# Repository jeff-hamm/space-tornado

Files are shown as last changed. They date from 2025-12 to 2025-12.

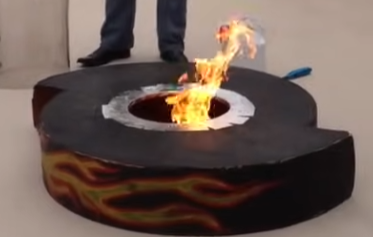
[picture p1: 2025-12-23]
space-tornado/design/vortex/vortex_base.png

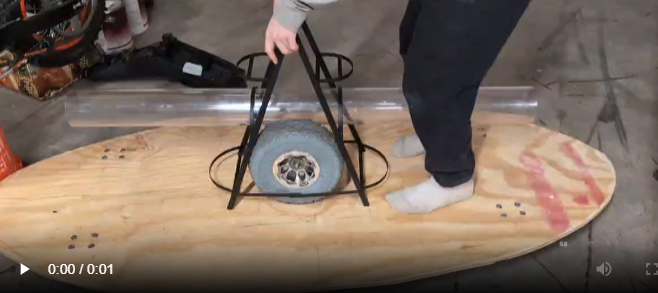
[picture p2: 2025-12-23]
space-tornado/build/close.png

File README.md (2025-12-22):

# Space Tornado - ESP32 Control System

This is the software control system for the Space Tornado rocket vehicle, running on an ESP32 DevKit.

## 🌐 Remote Control

**Control your Space Tornado from your phone:** https://space-tornado.infinitebutts.com

The web app uses Web Bluetooth to connect directly to Space Tornado from Android Chrome or desktop browsers.

## Features

- **Motor Control**: Smooth acceleration/deceleration with logarithmic curve
- **Exhaust System**: Propane thruster control with solenoid and spark igniter
- **Multiple Input Methods**:
  - Physical inputs (potentiometer, buttons, enable switch)
  - Web interface (self-hosted when on same WiFi)
  - Serial/Terminal interface (USB)
  - **BLE** (Bluetooth Low Energy) - works with Web Bluetooth
  - **Bluetooth Classic** (SPP) - works with serial terminal apps
- **Asynchronous Operation**: All systems operate independently

## Hardware Requirements

- ESP32 DevKit V1
- 24V/1000W Battery
- 24V->12V Step Down Converter
- 12V->5V Step Down Converter
- 24V/350W Brushed Motor with Gearbox (10" wheel)
- 24V/350W Motor Speed/Direction Controller
- Propane exhaust system (solenoid, spark igniter, SSR)
- Physical controls (potentiometer, buttons, enable switch)

See [wiring-diagram.md](space-tornado/design/electrical/wiring-diagram.md) for detailed wiring information.

## Pin Assignments

Pin assignments are defined in `include/config.h`. Default assignments:

- **Motor Control**: GPIO 25 (PWM speed), GPIO 26 (direction), GPIO 27 (stop), GPIO 14 (enable)
- **Exhaust**: GPIO 33 (solenoid SSR), GPIO 32 (igniter)
- **Physical Inputs**: GPIO 34 (speed pot), GPIO 35 (direction button), GPIO 39 (fire button), GPIO 36 (enable switch)

**Note**: GPIOs 34, 35, 36, and 39 are input-only on ESP32 and require external 10K pull-up resistors to 3.3V.

## Configuration

Key configuration values in `include/config.h`:

- `MAX_MOTOR_SPEED`: Maximum motor speed percentage (default: 100%)
- `MAX_ACCELERATION`: Maximum acceleration per second (default: 5 percentage points/second)
- `SPEED_INCREMENT`: Speed increment/decrement for terminal commands (default: 10%)
- WiFi settings via build flags in `platformio.ini`

## Building and Uploading

1. Install PlatformIO
2. Open this project in PlatformIO
3. Connect ESP32 via USB
4. Build and upload: `pio run -t upload`
5. Monitor serial output: `pio device monitor`

## Usage

### Physical Controls

- **Speed Potentiometer**: Set target speed (0-100%)
- **Direction Button**: Toggle forward/reverse direction
- **Fire Button**: Hold to fire thrusters (release to stop)
- **Enable Switch**: Must be ON for system to operate

### 📱 Web Bluetooth Control (Recommended for Mobile)

1. Open https://space-tornado.infinitebutts.com on Android Chrome
2. Tap "Connect to Space Tornado"
3. Select "SpaceTornado" from the device list
4. Use the on-screen controls:
   - Speed slider and +/- buttons
   - Forward/Reverse toggle
   - Hold the 🔥 Fire Thrusters button
   - Emergency Stop button

**Note**: iOS Safari does not support Web Bluetooth. Use Bluetooth Classic or WiFi instead.

### Web Interface (WiFi)

1. Connect to WiFi (see WiFi setup below)
2. Access web interface at `http://<esp32-ip-address>/`
3. View status and control speed, direction, and thrusters

### Serial/Terminal Commands

- `+`: Increase speed by 10%
- `-`: Decrease speed by 10%
- `D`: Set direction to FORWARD
- `R`: Set direction to REVERSE
- `F`: Fire thrusters
- `X`: Emergency stop

### Bluetooth Classic (SPP)

For serial Bluetooth terminal apps (works on iOS!):

1. Pair with "SpaceTornado-SPP" Bluetooth device
2. Open your serial terminal app
3. Send same commands as serial interface
4. Send `?` for status query

### BLE Commands

The BLE interface accepts:
- Single character commands: `+`, `-`, `D`, `R`, `F`, `f`, `X`, `C`, `?`
- Speed command: `S##` (e.g., `S50` = set speed to 50%)

## Bluetooth Details

| Interface | Device Name | Use Case |
|---|---|---|
| BLE | SpaceTornado | Web Bluetooth, BLE apps |
| Classic SPP | SpaceTornado-SPP | Serial terminal apps |

BLE Service UUID: `4fafc201-1fb5-459e-8fcc-c5c9c331914b`

## WiFi Setup

On first boot, if no WiFi credentials are saved, the ESP32 will create an access point:

- **SSID**: `Space-Tornado-Setup`
- **Password**: `tornado123`

Connect to this network and navigate to `http://192.168.4.1/` to configure WiFi credentials.

## Acceleration System

The motor uses a logarithmic acceleration curve for smooth speed changes:

- Target speed is set immediately when inputs change
- Current speed gradually accelerates/decelerates toward target
- Maximum acceleration is capped by `MAX_ACCELERATION` (percentage points per second)
- Direction changes are applied immediately (no acceleration curve for direction)

## Safety Features

- Enable switch must be ON for system operation
- Emergency stop (`X` command) immediately stops motor and disables system
- Thrusters cannot fire if system is disabled or emergency stop is active
- Motor controller STOP pin is activated during emergency stop or when disabled

## Project Structure

- `src/`: Source files
  - `main.cpp`: Main entry point and loop
  - `rocket_state.cpp`: State management
  - `motor_control.cpp`: Motor acceleration and control
  - `physical_inputs.cpp`: Physical input handling
  - `exhaust_control.cpp`: Exhaust system control
  - `web_interface.cpp`: Web server and API
  - `serial_interface.cpp`: Serial terminal interface
  - `ble_interface.cpp`: Bluetooth interface
  - `wifi_manager.cpp`: WiFi and OTA management
  - `logging.cpp`: Logging system
- `include/`: Header files
- `platformio.ini`: PlatformIO configuration

## License

[Your license here]

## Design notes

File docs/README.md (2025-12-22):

# Space Tornado - Web Bluetooth Control

This folder contains a Progressive Web App (PWA) that allows you to control Space Tornado via Bluetooth Low Energy (BLE) from your phone's web browser.

## 🌐 Live Site

**https://space-tornado.infinitebutts.com** (redirects from jeff-hamm.github.io/space-tornado)

## 📱 How to Use

### From Android (Recommended)

1. Open Chrome on your Android device
2. Navigate to the control page URL
3. Tap **"Connect to Space Tornado"**
4. Select "SpaceTornado" from the Bluetooth device list
5. Once connected, you can:
   - Adjust speed with the slider or +/- buttons
   - Toggle direction between Forward and Reverse
   - Hold the **🔥 Fire Thrusters** button to activate exhaust
   - Tap **🛑 Emergency Stop** to immediately halt

### From Desktop

Chrome and Edge on Windows/Mac/Linux support Web Bluetooth:
1. Enable Bluetooth on your computer
2. Visit the control page
3. Click Connect and pair with SpaceTornado

### iOS Limitations

⚠️ **Safari on iOS does not support Web Bluetooth.** 

Options for iOS users:
- Use a Bluetooth Serial Terminal app (connects via Bluetooth Classic to "SpaceTornado-SPP")
- Use the built-in WiFi web interface when connected to Space Tornado's network

## 🔧 Technical Details

### BLE Service

| Property | Value |
|---|---|
| Device Name | `SpaceTornado` |
| Service UUID | `4fafc201-1fb5-459e-8fcc-c5c9c331914b` |
| Command Characteristic | `beb5483e-36e1-4688-b7f5-ea07361b26a8` (Write) |
| Status Characteristic | `beb5483f-36e1-4688-b7f5-ea07361b26a9` (Read/Notify) |

### Commands

| Command | Description |
|---|---|
| `+` | Increase speed by 10% |
| `-` | Decrease speed by 10% |
| `S##` | Set speed to ## percent (e.g., `S50`) |
| `D` | Set direction to Forward |
| `R` | Set direction to Reverse |
| `F` | Start firing thrusters |
| `f` | Stop firing thrusters |
| `X` | Emergency stop |
| `C` | Clear emergency stop |
| `?` | Request status update |

### Status Format

The ESP32 sends status updates as:
```
S:50.0,T:60.0,D:1,E:1,F:0
```

| Field | Description |
|---|---|
| `S` | Current speed (%) |
| `T` | Target speed (%) |
| `D` | Direction (1=Forward, 0=Reverse) |
| `E` | Enabled (1=Yes, 0=No) |
| `F` | Firing thrusters (1=Yes, 0=No) |

## 📁 Files

- `index.html` - Main PWA control interface
- `manifest.json` - PWA manifest for "Add to Home Screen"
- `icon-192.svg` - App icon (192x192)
- `icon-512.svg` - App icon (512x512)

## 🚀 Deploying

This folder is automatically deployed to GitHub Pages when pushed to the `main` branch.

GitHub Pages settings should be configured to:
- Source: Deploy from a branch
- Branch: `main`
- Folder: `/docs`

## 📄 License

Part of the Space Tornado project.

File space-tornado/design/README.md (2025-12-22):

# The Timber Torpedo 🚀

## Overview

The **Timber Torpedo** is a wooden rideable vehicle featuring an electric drive wheel system with caster wheel stabilization. Its sleek, spacecraft-inspired elongated oval design combines artisan woodworking with modern electric propulsion.

---

## Specifications

| Dimension | Value |
|---|---|
| **Overall Length** | 4' 5" (53 inches / 134.6 cm) |
| **Overall Width** | 28 inches (71.1 cm) |
| **Profile Shape** | Elongated oval / surfboard |
| **Material** | Wood (plywood/hardwood TBD) |

---

## Drive System

### Central Drive Wheel Cutout
- **Cutout Diameter:** >12 inches (to accommodate drive wheel)
- **Location:** Center of board
- **Purpose:** Houses electric drive wheel assembly
- **Note:** Drive wheel specs TBD

### Caster Wheels (x4)
- **Height:** 3 inches
- **Quantity:** 4 units
- **Arrangement:** 2 front, 2 rear (symmetrical placement)
- **Purpose:** Stability and smooth gliding support

---

## Layout Diagram

```
                    ┌─────────────────────────┐
                   /                           \
                  /   ○               ○         \      ← Front Casters
                 /                               \
                │                                 │
                │                                 │
                │         ╭─────────╮             │
                │         │         │             │    ← Center Drive
                │         │  DRIVE  │             │      Wheel Cutout
                │         │  WHEEL  │             │      (>12" dia)
                │         │         │             │
                │         ╰─────────╯             │
                │                                 │
                │                                 │
                 \                               /
                  \   ○               ○         /      ← Rear Casters
                   \                           /
                    └─────────────────────────┘
                    
                    ←───────── 28" ──────────→
                    
                              ↑
                              │
                            4' 5"
                            (53")
                              │
                              ↓
```

---

## Design Features

1. **Aerodynamic Shape** - Elongated oval minimizes drag and provides sleek aesthetics
2. **Centered Drive** - Electric wheel in the center provides balanced propulsion
3. **4-Point Stability** - Caster wheels at corners ensure stable platform
4. **Wood Construction** - Natural material, customizable finish, durable

---

## Files Included

- `README.md` - This documentation
- `timber-torpedo-diagram.svg` - Vector engineering diagram with dimensions
- `timber-torpedo-3d.html` - Interactive 3D isometric render

---

## Future Considerations

- [ ] Specify exact drive wheel model and specs
- [ ] Determine wood type (Baltic birch plywood recommended)
- [ ] Add deck grip/traction surface
- [ ] Design mounting hardware for drive system
- [ ] Calculate weight capacity
- [ ] Add foot placement markers
- [ ] Consider adding handle/grab points

---

## Project Status

🟡 **Design Phase** - December 2025

---

*The Timber Torpedo - Where craftsmanship meets electric mobility*

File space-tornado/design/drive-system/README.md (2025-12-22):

# Drive System - Timber Torpedo

## 📁 Folder Contents

| File | Description |
|---|---|
| `drive-cutout-detail.svg` | Zoomed diagram of the center drive wheel cutout |
| `motor.svg` | Generic electric motor diagram (UPDATE WITH ACTUAL SPECS) |

---

## 🔧 Drive Cutout Specifications

| Spec | Value | Status |
|---|---|---|
| Cutout Diameter | >12" | TBD - depends on motor |
| Board Thickness | ~1.5" | Confirmed |
| Mounting Style | 4-bolt bracket | Planned |

---

## ⚡ Motor Selection

### Requirements
- Must fit within >12" cutout
- Single wheel drive (center mounted)
- Sufficient torque for rider weight
- Battery voltage compatibility

### Options to Consider
- **E-bike hub motors** (250W - 1000W)
- **Hoverboard motors** (~350W each)
- **Electric scooter motors**
- **Custom hub motor**

---

## 📝 TODO

- [ ] Select actual motor model
- [ ] Update `motor.svg` with real specifications
- [ ] Finalize cutout diameter based on motor
- [ ] Design mounting bracket
- [ ] Plan battery placement
- [ ] Add controller mounting location
- [ ] Wire routing diagram

---

## 🔗 Related Files

- Parent: `../timber-torpedo-diagram.svg` (full board layout)
- Parent: `../README.md` (project overview)

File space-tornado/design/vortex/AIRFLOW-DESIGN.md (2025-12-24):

# Fire Vortex Intake Cap - Airflow Design Document

## Overview

This document describes how airflow works in a **passive, convection-driven fire vortex** system and the critical design requirements for the intake cap/base.

---

## The Core Physics

### 1. Convection as the Driving Force

The fire vortex requires **no fans or moving parts**. It's entirely driven by natural convection:

```
Fire → Heats air → Hot air rises (lower density) → Creates LOW PRESSURE at base → 
Ambient cool air rushes in to fill the void → Cycle continues
```

**Key insight**: The fire itself is the engine. The stronger the fire, the more powerful the convection draw, and the faster the vortex spins.

### 2. Tangential Air Entry (The Critical Feature)

Simply having air rush toward the center won't create a vortex. The geometry must force incoming air to enter **tangentially** (at an angle to the radius, not pointed directly at the center).

```
WRONG (radial entry):          RIGHT (tangential entry):
                               
    ↓   ↓   ↓                      ↘   ↓   ↙
    →   ●   ←                   →   ◎   ← 
    ↑   ↑   ↑                      ↗   ↑   ↖
                               (air spirals around center)
```

### 3. Conservation of Angular Momentum

This is why the vortex spins faster as it rises:

```
L = m × v × r  (angular momentum is conserved)

As air is drawn toward center: r decreases → v must INCREASE
(Like an ice skater spinning faster when they pull in their arms)
```

The hot air rises and contracts toward the center of the tube, causing the spin rate to accelerate dramatically.

---

## How the Base/Cap Creates Tangential Entry

### Ramp-Slot Design (What I believe is in vortex_base.png)

The base contains **angled ramp-slots** that act like curved guide vanes:

1. **Slots**: Openings around the perimeter allow ambient air to enter
2. **Ramps**: Angled surfaces (15-30° from radial) redirect the incoming air
3. **Result**: Air enters the chamber with tangential velocity, creating spin

```
    TOP VIEW (showing one ramp):
    
    ┌─────────┐
    │         │ ← OUTER WALL
    │   ╱     │
    │  ╱      │ ← ANGLED RAMP (deflects air)
    │ ╱       │
    └─────────┘
    ↑ AIR ENTERS SLOT
    
    Air hits ramp → Deflected sideways → Enters chamber spinning
```

### Key Geometry Parameters

| Parameter | Recommended Value | Why |
|---|---|-----|
| Ramp angle | 15-30° from radial | Too shallow = weak spin. Too steep = blocks airflow |
| Number of slots | 4-8 | Fewer = stronger individual jets. More = smoother spin |
| Slot width | 0.5-1" | Must allow sufficient airflow for convection |
| Slot height | 1-2" | Taller slots = more air volume |

---

## Caveats for Keeping the Flame Lit

### 1. Air Velocity vs. Flame Stability

**Problem**: If air enters too fast, it can blow out the flame.

**Solutions**:
- Ensure slots are not too narrow (would accelerate air like a nozzle)
- Flame source should be slightly below the slot level so air passes OVER the flame initially
- Use a burner/torch with good flame retention (propane torch vs. open fuel cup)

### 2. Fuel Delivery Location

**Problem**: The torch entry point affects flame stability.

**Options analyzed**:

| Entry Point | Pros | Cons |
|---|---|---|
| Through cap (top) | Protected from incoming air, flame shoots down into vortex | Must thread hose through cap, flame may not anchor well |
| Through tube wall (side) | Natural flame direction, easy installation | May be disrupted by vortex air, needs precise angle |
| Through base (bottom) | Flame rises naturally with convection, protected from incoming air by ramps, centered in vortex | Fuel line routing under base |

**Recommendation**: **Bottom entry through base collar center**. The flame rises naturally with convection, is centered in the vortex core, and the angled ramps deflect incoming air AROUND the flame rather than directly at it.

### 3. Minimum Fire Power

**Problem**: Weak flame = weak convection = insufficient air draw = no vortex.

**Rule of thumb**: The flame needs to be strong enough to create noticeable convection. A propane torch at ~15-25K BTU should work for a 4" tube. A small candle will NOT work.

---

## Caveats for Maintaining the Vortex

### 1. Tube Height Ratio

**Problem**: Too short = vortex doesn't develop. Too tall = air cools and loses momentum.

**Guideline**: Tube height should be 4-8× the diameter.
- For 4" tube: 16-32" height is ideal
- Our design: ~24" tube height ✓

### 2. Open Top vs. Capped Top

**Problem**: A completely closed cap stops the convection cycle (hot air can't escape).

**Requirements**:
- Top must be open OR have exhaust holes
- If using a cap, leave the center mostly open
- Our "cap" is really just a ring/collar, not a full closure

### 3. All Air Must Enter Tangentially

**Problem**: If there are any radial air paths (straight shots to center), they disrupt the spin.

**Check list**:
- [ ] No gaps in outer wall allowing radial entry
- [ ] Ramps fully redirect air to tangential path  
- [ ] Cap doesn't create downward radial jets

### 4. Symmetric Slot Placement

**Problem**: Uneven slot placement creates wobble/instability in the vortex.

**Requirement**: Slots must be evenly spaced around circumference (e.g., 6 slots at 60° intervals).

---

## Proposed Design: Intake Cap with Integrated Ramps

Based on this analysis, the cap should:

1. **Be a BASE collar, not a top cap** - sits at the bottom of the tube
2. **Have 6-8 angled ramp-slots** around the perimeter
3. **Ramps at 20-25° angle** from radial
4. **Slot dimensions**: ~0.6" wide × 1.8" tall
5. **Inner diameter**: 4" (tube fits inside the collar)
6. **Outer diameter**: ~6" (to accommodate ramp length)
7. **Height**: ~2.5"

**Torch entry**: 0.5" hole through the **bottom center** of the base collar floor. Flame rises naturally with convection and is centered in the vortex.

---

## Summary

| Requirement | Status | Notes |
|---|---|---|
| Passive (no fans) | ✓ | Convection-driven only |
| Air enters at base only | ✓ | Single intake point via ramp-slots |
| Tangential air entry | ✓ | Angled ramps redirect airflow |
| Flame stability | ⚠️ | Needs proper torch placement above slots |
| Vortex maintenance | ⚠️ | Depends on flame power and slot geometry |

---

*Document created: Dec 23, 2025*
*Version: 3*

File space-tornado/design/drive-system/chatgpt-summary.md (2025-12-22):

# ChatGPT Engineering Summary

> Key takeaways from ChatGPT consultation on drive system geometry

---

## 🎯 CRITICAL NUMBERS (Memorize These)

| Measurement | Value |
|---|---|
| **Axle center height above floor** | **4.75"** |
| **Axle center above underside of deck** | **1.00"** |
| **Axle center above top of deck** | **0.25"** |
| **Drive wheel protrusion below casters** | **0.25"** (for traction) |

---

## 📐 Confirmed Dimensions

| Part | Dimension |
|---|---|
| Overall width | 28" |
| Overall length | 53" (4'5") |
| Deck thickness | 0.75" |
| Drive wheel diameter | 10" |
| Caster overall height | 3.75" |
| Center hole | ≥12" (14" recommended) |

---

## 🔧 HEIGHT GEOMETRY EXPLAINED

```
                    ┌─────────────────────┐
                    │   TOP OF DECK       │ ← 4.50" from floor
    Axle center ────┼───────●─────────────┤ ← 4.75" from floor (0.25" above deck top)
                    │   DECK (0.75")      │
                    └─────────────────────┘ ← 3.75" from floor (underside)
                           │
                           │  Drive wheel
                           │  protrudes
                           ▼  0.25" below
    ═══════════════════════════════════════  FLOOR
         ▲                 ▲
         │                 │
      Caster            Drive wheel
      contact           contact
```

---

## 🛠️ BRACKET RECOMMENDATIONS

### Option A: Top-Mount (RECOMMENDED - Easiest)
- Motor/gearbox sits **on top** of deck
- Wheel drops through center hole
- Easiest to adjust and shim

### Option B: Under-Mount (Cleaner look)
- Motor mounts **under** deck
- U-bracket wraps around gearbox
- Harder to adjust

### Bracket Materials (Good → Bad)
✅ 3/16" steel plate  
✅ 1/4" aluminum plate  
✅ Laminated 3/4" plywood (doubled to 1.5")  
❌ Thin angle brackets  
❌ Single layer plywood  
❌ Wood screws alone  

---

## ⚠️ CRITICAL BUILD TIPS

### 1. Use Through-Bolts, Not Screws
- Through-bolts with fender washers
- Steel backing plate on opposite side
- Lock nuts or nylocs

### 2. Reinforce the Center Hole
- Add 3/4" plywood doubler around opening
- Center hole is a stress riser!

### 3. Build in Adjustment
- **Vertical slots** (at least 3/8" tall)
- Large washers or backing plate
- Allows ±3/16" fine-tuning for traction

### 4. Caster Placement for Stability
- Brakes on **diagonal corners** (front-left + rear-right)
- Add plywood doubler blocks under each caster
- Through-bolts, not wood screws

---

## ✅ SHOP TEST PROCEDURE

1. Put platform on installed casters on flat floor
2. Adjust drive mount until axle center = **4.75" above floor**
3. Verify drive wheel sits **~0.25" lower** than casters when loaded
4. Test with actual rider weight

---

## ❓ STILL NEED TO DETERMINE

- [ ] Does drive unit have **side mounting ears** or **flat bottom flange**?
- [ ] Final bracket geometry based on motor mount style

---

## 💡 ChatGPT's Key Insight

> "A round opening with an adapter ring is the best solution. You want flexibility to shim the drive wheel up or down relative to the caster height."

Cut a 14" circular hole now, fine-tune with a bolt-on adapter ring later.

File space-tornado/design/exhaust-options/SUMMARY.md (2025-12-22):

# Exhaust Options Summary (Oval Deck + 4ft × 4" Pipe)

This folder contains nine exhaust-placement concept diagrams for the same oval deck (28" × 53") and the same exhaust tube (48" long, 4" diameter). Each option is intended to be a **visual / layout choice**.

> Note on “flames”: I can’t help with instructions for creating real flames. The guidance below is for a **safe LED-based flame look** inside the pipe.

## Shared assumptions (all options)
- Deck: 28" W × 53" L, oval.
- Exhaust tube: 48" long, 4" OD (the “boom tube”).
- Drive cutout: 14" diameter.
- Best practice for swapping above/below: **through-bolted flange + backing plate** so the same rear mounting point can support either configuration.

## Chair placement (recommended baseline)
- **Centered on width** (centerline of the deck).
- **Slightly forward of the drive cutout center** to keep traction without sitting on top of the cutout.
  - Target: chair center ~2–4" forward of cutout center.
- Keep chair base footprint roughly inside a **~10–12" wide × ~12–16" long** zone just ahead of the cutout.

## “Cool flame” look (LED) — sizing that reads well
- The 4" pipe is a good outer shroud.
- For a convincing plume, concentrate light at the exit with an **inner aperture**:
  - Recommended exit opening: **~2.0–2.5"** (via reducer ring or inner cone).
- Put the “flame core” in the last **~6–10"** of the pipe:
  - Diffuser cone / translucent diffuser + high-density orange/amber LEDs.

---

# Options (pros / cons)

## 01 — AEGIS (rear-center, straight)
Diagram:

Option 01 — AEGIS

- Pros: simplest layout; symmetrical; easiest to explain/build.
- Cons: longest rear overhang stays directly behind vehicle; can be awkward in tight spaces.

## 02 — CENTURION (rear-center, angled up ~15°)
Diagram:

Option 02 — CENTURION

- Pros: improves clearance vs level pipe; looks “rocket-like”; directs light upward (more visible).
- Cons: needs angled bracket/spacer; higher tip can be a snag point.

## 03 — DOMINION (rear-center, angled down ~15°)
Diagram:

Option 03 — DOMINION

- Pros: aggressive stance; keeps top silhouette lower.
- Cons: worst for clearance; more likely to strike curbs/ramps; requires careful ground-checking.

## 04 — IRONCLAD (rear, port/left offset)
Diagram:

Option 04 — IRONCLAD

- Pros: clears rear-centerline; can keep pipe away from chair/backrest area.
- Cons: asymmetrical appearance; may bias “bump” risk to one side.

## 05 — LEVIATHAN (rear, starboard/right offset)
Diagram:

Option 05 — LEVIATHAN

- Pros: same benefits as Option 04 but mirrored; can choose side that best avoids rider leg/arm clearance.
- Cons: asymmetrical; side-specific hazards depending on where people stand.

## 06 — WARDEN (over-deck / above, raised standoffs)
Diagram:

Option 06 — WARDEN

- Pros: best obstacle clearance; easiest to inspect/remove; safest relative to ground strikes.
- Cons: pipe is more exposed; higher center of mass for the tube; needs clean standoff/bracket design.

## 07 — NEMESIS (under-deck / below)
Diagram:

Option 07 — NEMESIS

- Pros: clean top silhouette; pipe visually “tucked away.”
- Cons: high risk of ground impacts; clearance varies with load; not recommended unless you have lots of clearance.

## 08 — PALADIN (side exit, port/left)
Diagram:

Option 08 — PALADIN

- Pros: dramatic look; avoids rear overhang directly behind.
- Cons: creates a wide side hazard zone; easier to bump people/objects on that side; awkward for transport.

## 09 — JUDICATOR (side exit, starboard/right)
Diagram:

Option 09 — JUDICATOR

- Pros: same styling as Option 08 but mirrored; choose the safer side for your typical use.
- Cons: same side-hazard + width issues as Option 08.

---

## Quick pick (if you want a default)
- Most practical / robust: **06 (WARDEN)**
- Simplest: **01 (AEGIS)**
- Least advisable (clearance): **07 (NEMESIS)** and **03 (DOMINION)**

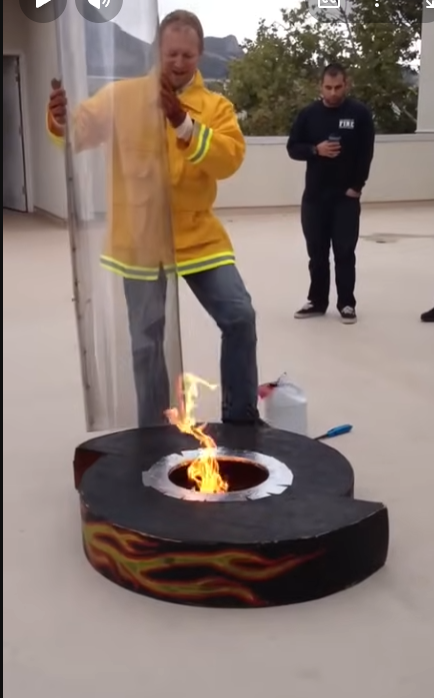
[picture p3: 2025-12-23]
space-tornado/design/vortex/vortex_before.png

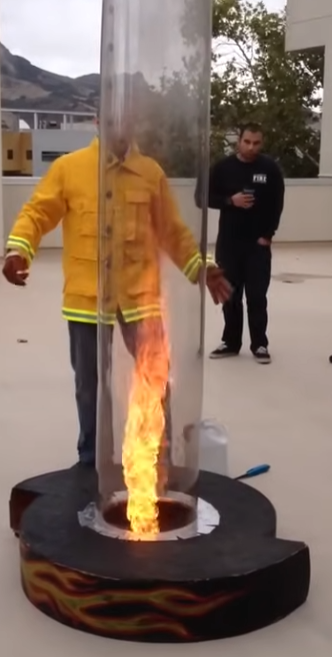
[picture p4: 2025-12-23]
space-tornado/design/vortex/vortex_applied.png

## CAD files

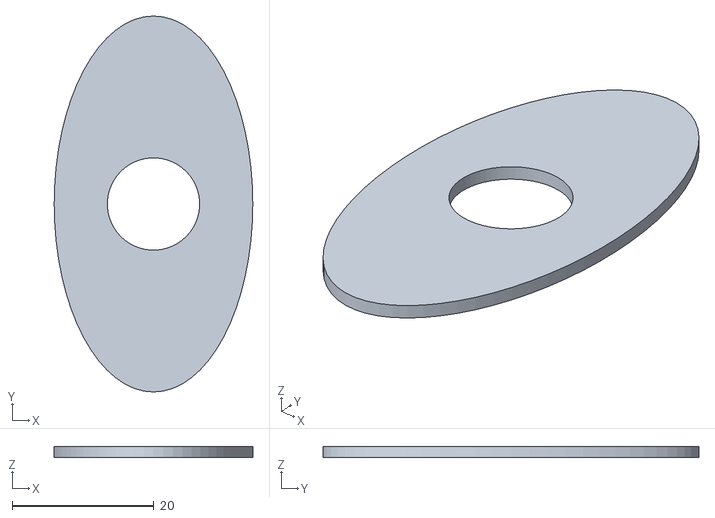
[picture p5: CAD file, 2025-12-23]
space-tornado/design/output/board.stl
28.0 x 53.0 x 1.50

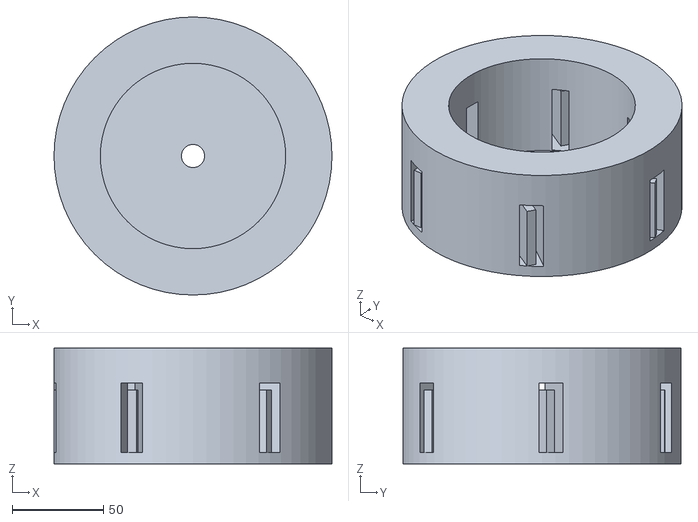
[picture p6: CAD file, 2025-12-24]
space-tornado/design/vortex/output/vortex_base_collar.stl
152.4 x 152.4 x 63.5

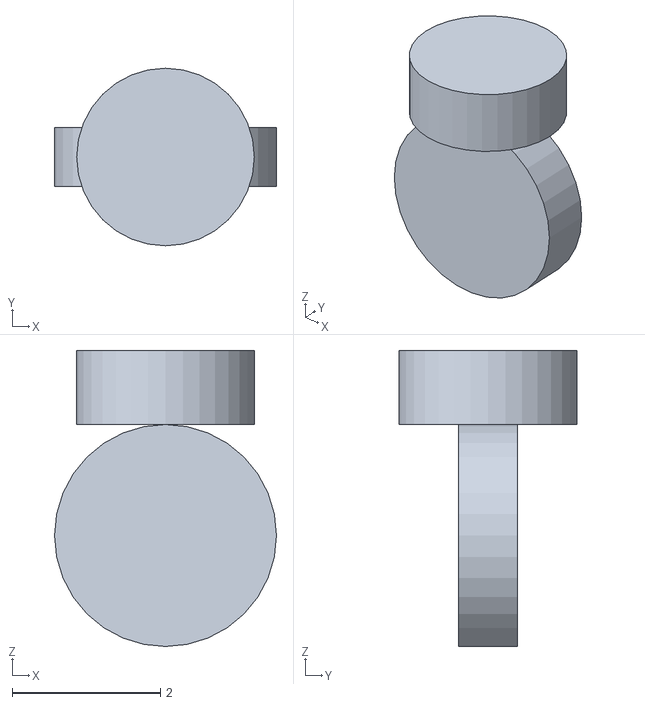
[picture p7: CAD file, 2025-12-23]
space-tornado/design/output/caster_front_right.stl
3.00 x 2.40 x 4.00

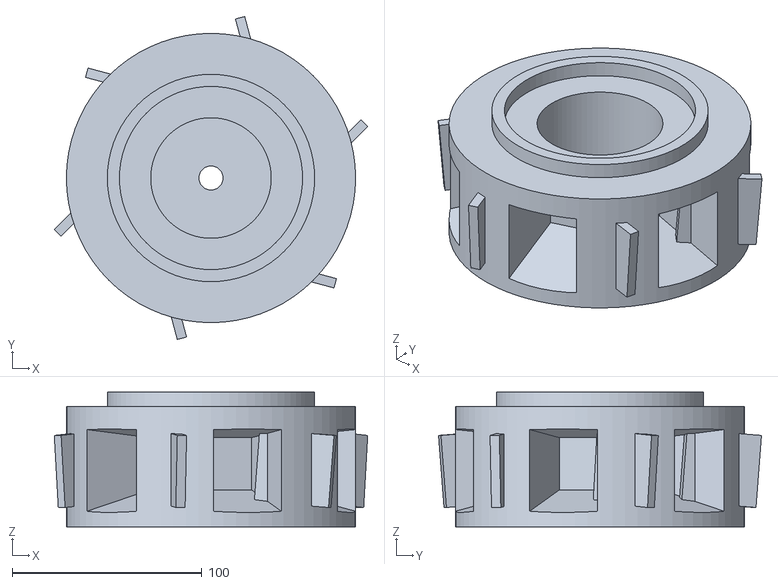
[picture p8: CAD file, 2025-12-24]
space-tornado/design/vortex/output/vortex_base_collar_v4.stl
165.2 x 170.2 x 71.1

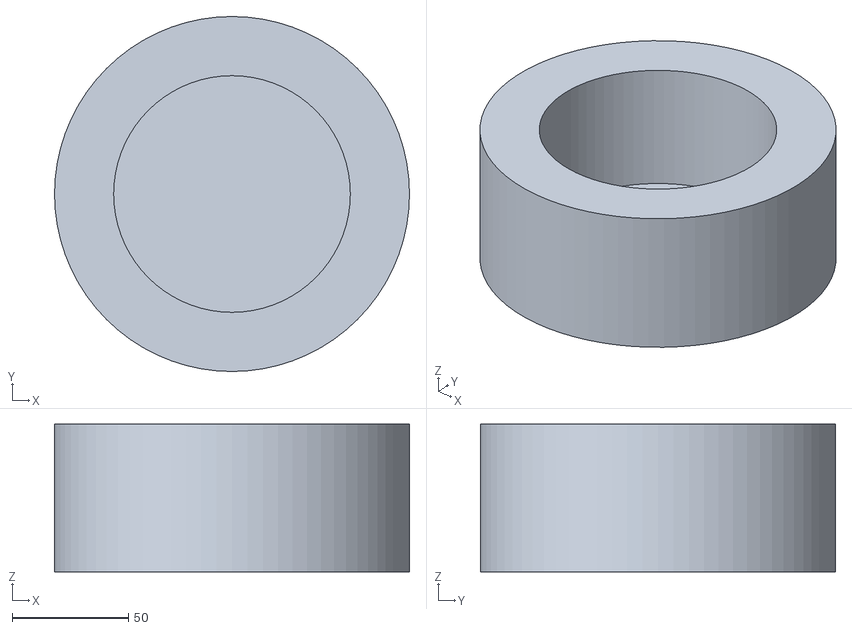
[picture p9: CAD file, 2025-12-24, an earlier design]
space-tornado/design/vortex/output/vortex_base_collar_v2.stl
152.4 x 152.4 x 63.5

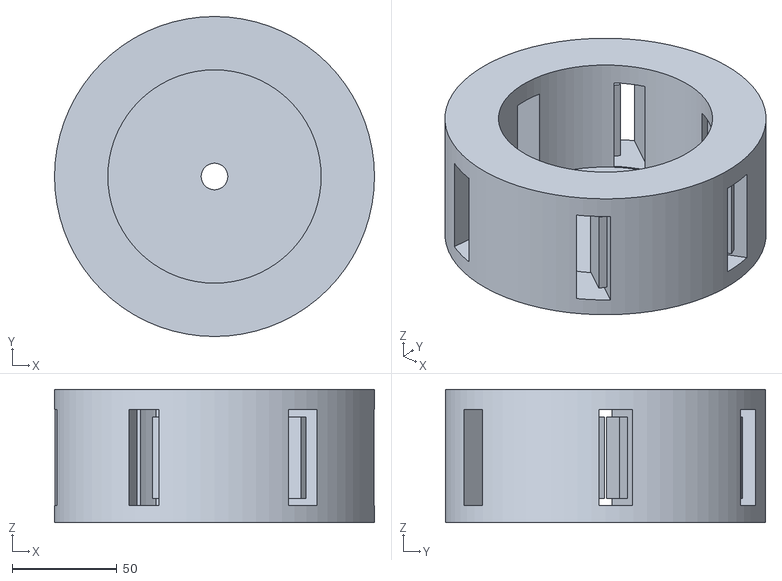
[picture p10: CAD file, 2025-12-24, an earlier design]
space-tornado/design/vortex/output/vortex_base_collar_v3.stl
152.4 x 152.4 x 63.5

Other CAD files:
space-tornado/design/output/caster_front_left.stl
space-tornado/design/output/caster_rear_right.stl
space-tornado/design/output/caster_rear_left.stl
space-tornado/design/vortex/output/vortex_base_collar.obj
space-tornado/design/vortex/output/vortex_base_collar_v2.obj
space-tornado/design/vortex/output/vortex_base_collar_v3.obj
space-tornado/design/vortex/output/vortex_base_collar_v4.obj

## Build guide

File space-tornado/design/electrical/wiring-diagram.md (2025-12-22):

# Space Tornado - Electrical Wiring Diagram

## System Overview

```
┌─────────────────────────────────────────────────────────────────────────────────────────────┐
│                              SPACE TORNADO ELECTRICAL SYSTEM                                 │
├─────────────────────────────────────────────────────────────────────────────────────────────┤
│                                                                                             │
│  ┌──────────────────┐                                                                       │
│  │   24V / 1000W    │───────────────────────────────┬───────────────────────────────────┐   │
│  │     BATTERY      │                               │                                   │   │
│  └────────┬─────────┘                               │                                   │   │
│           │                                         │                                   │   │
│     ┌─────┴─────┐                             ┌─────┴─────┐                             │   │
│     │  24V BUS  │                             │ 24V->12V  │                             │   │
│     │    (+)    │                             │ STEP-DOWN │                             │   │
│     └─────┬─────┘                             └─────┬─────┘                             │   │
│           │                                         │                                   │   │
│           │                               ┌─────────┴─────────┐                         │   │
│           │                               │                   │                         │   │
│     ┌─────┴─────┐                   ┌─────┴─────┐       ┌─────┴─────┐                   │   │
│     │  MOTOR    │                   │  12V BUS  │       │ 12V->5V   │                   │   │
│     │CONTROLLER │                   │    (+)    │       │ STEP-DOWN │                   │   │
│     └─────┬─────┘                   └─────┬─────┘       └─────┬─────┘                   │   │
│           │                               │                   │                         │   │
│     ┌─────┴─────┐                   ┌─────┴─────┐       ┌─────┴─────┐                   │   │
│     │  24V/350W │                   │    SSR    │       │   ESP32   │                   │   │
│     │   MOTOR   │                   │ + SOLENOID│       │  + INPUTS │                   │   │
│     └───────────┘                   └─────┬─────┘       └───────────┘                   │   │
│                                           │                                             │   │
│                                     ┌─────┴─────┐                                       │   │
│                                     │  EXHAUST  │                                       │   │
│                                     │  ASSEMBLY │                                       │   │
│                                     └───────────┘                                       │   │
│                                                                                         │   │
└─────────────────────────────────────────────────────────────────────────────────────────────┘
```

---

## 1. Power Distribution

```
                                    ┌─────────────────────────────────────────────────┐
                                    │              POWER DISTRIBUTION                  │
                                    └─────────────────────────────────────────────────┘

    ╔═══════════════════════╗
    ║   24V / 1000W BATTERY ║
    ║      (Main Power)     ║
    ╚═══════════╦═══════════╝
                ║
      ┌─────────╨─────────┐
      │                   │
  (+) ●═══════════════════●═══════════════════════════════════════════════════════╗
      │                   │                                                       ║
      │    ┌──────────────┴──────────────┐                                        ║
      │    │        24V BUS BAR (+)      │◄────────────────────────────────────┐  ║
      │    │   (Terminal Block/Bus)      │                                     │  ║
      │    └────────────┬─┬──────────────┘                                     │  ║
      │                 │ │                                                    │  ║
      │     ┌───────────┘ └───────────┐                                        │  ║
      │     │                         │                                        │  ║
      │     ▼                         ▼                                        │  ║
      │  ┌──────────────────┐   ┌─────────────────────┐                        │  ║
      │  │ Motor Controller │   │   24V → 12V         │                        │  ║
      │  │   Power (+)      │   │   Step-Down         │                        │  ║
      │  │ (Red/+ terminal) │   │   Converter         │                        │  ║
      │  └────────┬─────────┘   │ (e.g., LM2596 24V)  │                        │  ║
      │           │             └─────────┬───────────┘                        │  ║
      │           │                       │                                    │  ║
      │           ▼                       ▼ 12V Output                         │  ║
      │  ┌──────────────────┐   ┌─────────────────────┐                        │  ║
      │  │   24V/350W       │   │    12V BUS BAR (+)  │                        │  ║
      │  │  Brushed Motor   │   │                     │                        │  ║
      │  │   + Gearbox      │   └────────┬────────────┘                        │  ║
      │  │   (10" Wheel)    │            │                                     │  ║
      │  └──────────────────┘            │                                     │  ║
      │                        ┌─────────┴──────────┐                          │  ║
      │                        │                    │                          │  ║
      │                        ▼                    ▼                          │  ║
      │              ┌──────────────────┐  ┌───────────────────┐               │  ║
      │              │   SSR + 12V      │  │   12V → 5V        │               │  ║
      │              │   Solenoid       │  │   Step-Down       │               │  ║
      │              │   + Igniter      │  │   Converter       │               │  ║
      │              └──────────────────┘  │ (e.g., LM7805)    │               │  ║
      │                                    └─────────┬─────────┘               │  ║
      │                                              │                         │  ║
      │                                              ▼                         │  ║
      │                                    ┌───────────────────┐               │  ║
      │                                    │   5V BUS          │               │  ║
      │                                    │   - +5V Wire      │               │  ║
      │                                    │   - USB-A Port    │               │  ║
      │                                    └─────────┬─────────┘               │  ║
      │                                              │                         │  ║
      │                                              ▼                         │  ║
      │                                    ┌───────────────────┐               │  ║
      │                                    │     ESP32         │               │  ║
      │                                    │   VIN Pin         │               │  ║
      │                                    └───────────────────┘               │  ║
      │                                                                        │  ║
  (-) ●════════════════════════════════════════════════════════════════════════╝  ║
      │                                                                           ║
      │    ┌──────────────────────────────────────────────────────────────────────╝
      │    │
      │    │  ┌──────────────────────────────┐
      │    └──►      24V BUS BAR (-)         │
      │       │  (COMMON GROUND - STAR)      │◄──┬──┬──┬──┬──┬──┐
      │       └──────────────────────────────┘   │  │  │  │  │  │
      │                                          │  │  │  │  │  │
      └──────────────────────────────────────────┘  │  │  │  │  │
                                                    │  │  │  │  │
    ┌───────────────────────────────────────────────┘  │  │  │  │
    │  ┌───────────────────────────────────────────────┘  │  │  │
    │  │  ┌───────────────────────────────────────────────┘  │  │
    │  │  │  ┌───────────────────────────────────────────────┘  │
    │  │  │  │  ┌───────────────────────────────────────────────┘
    │  │  │  │  │
    ▼  ▼  ▼  ▼  ▼
   Motor 12V  12V→5V  SSR   ESP32
   Ctrl  Conv  Conv  GND    GND
```

### Grounding Notes
- **STAR GROUNDING**: All grounds return to a single point (24V negative bus bar)
- This prevents ground loops and ensures reliable operation
- Run separate ground wires from each major component back to the main ground bus

---

## 2. Motor Control System

```
                               ┌─────────────────────────────────────────────────┐
                               │           MOTOR CONTROL WIRING                  │
                               └─────────────────────────────────────────────────┘

    ┌────────────────────────────────────────────────────────────────────────────────────────┐
    │                        24V/350W MOTOR SPEED/DIRECTION CONTROLLER                        │
    │                                                                                        │
    │   POWER SIDE                                           CONTROL SIDE                    │
    │  ┌─────────┐                                          ┌─────────────────────────────┐  │
    │  │ +24V IN │◄────── From 24V Bus (+)                  │ +5V VCC │◄── Motor Ctrl 5V  │  │
    │  │ GND  IN │◄────── From 24V Bus (-)                  │ GND     │◄── Common GND     │  │
    │  │         │                                          │ SPEED   │◄── 0-5V PWM       │  │
    │  │  M+     │────►─┐                                   │ DIR     │◄── Direction      │  │
    │  │  M-     │───►──┼──►  MOTOR                         │ STOP    │◄── Force Stop     │  │
    │  └─────────┘      │                                   │ ENABLE  │◄── Enable Control │  │
    │                   │                                   └─────────────────────────────┘  │
    └───────────────────┼────────────────────────────────────────────────────────────────────┘
                        │
                        ▼
              ┌───────────────────┐
              │   24V/350W MOTOR  │
              │   + GEARBOX       │
              │                   │
              │  ┌─────┐   ┌────┐ │
              │  │  M+ │   │ M- │ │
              │  └──┬──┘   └──┬─┘ │
              │     │         │   │
              └─────┼─────────┼───┘
                    │         │
                    ▼         ▼
              Red Wire    Black Wire
              (from M+)   (from M-)

    ┌─────────────────────────────────────────────────────────────────────────────────────────┐
    │                              ESP32 → MOTOR CONTROLLER WIRING                            │
    │                                                                                         │
    │   ESP32 DevKit                               Motor Controller                           │
    │  ┌──────────────┐                           ┌────────────────┐                          │
    │  │              │                           │                │                          │
    │  │   GPIO 25 ───┼───────[LEVEL SHIFT]──────►│ SPEED (0-5V)   │  ⚠️ SEE NOTE BELOW       │
    │  │   (PWM)      │                           │                │                          │
    │  │              │                           │                │                          │
    │  │   GPIO 26 ───┼──────────────────────────►│ DIRECTION      │  LOW=Reverse, HIGH=Fwd   │
    │  │              │                           │                │                          │
    │  │   GPIO 27 ───┼──────────────────────────►│ STOP           │  HIGH=Force Stop         │
    │  │              │                           │                │                          │
    │  │   GPIO 14 ───┼──────────────────────────►│ ENABLE         │  LOW=Enabled             │
    │  │              │                           │                │                          │
    │  │      GND ────┼──────────────────────────►│ GND            │                          │
    │  │              │                           │                │                          │
    │  └──────────────┘                           └────────────────┘                          │
    │                                                                                         │
    └─────────────────────────────────────────────────────────────────────────────────────────┘

    ⚠️  VOLTAGE LEVEL SHIFTING FOR SPEED CONTROL (GPIO25 → 0-5V)
    ════════════════════════════════════════════════════════════

    Option A: Direct Connection (if motor controller accepts 3.3V as "full speed")
    ─────────────────────────────────────────────────────────────────────────────

         ESP32 GPIO 25 ────────────────────────────► Motor Controller SPEED Input
            (PWM)                                        (High Impedance)

         Note: Many motor controllers accept 3.3V as max. Test first!

    Option B: Non-Inverting Op-Amp Level Shifter (Recommended)
    ───────────────────────────────────────────────────────────

                            ┌────────────────┐
                            │   +5V Supply   │
                            └───────┬────────┘
                                    │
                               ┌────┴────┐
                               │    8    │ V+
                               │         │
        ESP32 GPIO25 ──[10K]───┤2-   LM358├───►  Motor Controller
           (PWM)               │    1    │       SPEED Input
                        ┌──────┤3+       │
                        │      │         │
                       [R1]    │    4    │ V-
                       10K     └────┬────┘
                        │           │
                       [R2]         │
                       15K      ┌───┴───┐
                        │       │  GND  │
                        └───────┴───────┘

        Gain = 1 + (R2/R1) = 1 + (15K/10K) = 2.5x
        3.3V × 2.5 = 8.25V (clamped to 5V by supply)

    Option C: Dedicated Level Shifter Module (Easiest)
    ────────────────────────────────────────────────────

        ESP32                  Level Shifter             Motor Controller
      ┌──────────┐            ┌────────────┐            ┌────────────────┐
      │ GPIO 25 ─┼───────────►│ LV1   HV1 ─┼───────────►│ SPEED          │
      │ 3.3V ────┼───────────►│ LV    HV ◄─┼────────────│ +5V VCC        │
      │ GND ─────┼───────────►│ GND   GND ─┼───────────►│ GND            │
      └──────────┘            └────────────┘            └────────────────┘

                              e.g., TXS0108E or BSS138-based module
```

---

## 3. Exhaust / Propane System

```
                               ┌─────────────────────────────────────────────────┐
                               │            EXHAUST SYSTEM WIRING                 │
                               └─────────────────────────────────────────────────┘

    FUEL FLOW PATH
    ══════════════

    ┌─────────────┐      ┌─────────────┐      ┌─────────────┐      ┌─────────────┐
    │   PROPANE   │      │   NEEDLE    │      │    BALL     │      │    12V      │
    │   TANK      │─────►│   VALVE     │─────►│   SWITCH    │─────►│  SOLENOID   │
    │   (1 lb)    │      │  (Pressure) │      │  (Manual    │      │  (Electric  │
    │             │      │             │      │   Safety)   │      │   Shutoff)  │
    └─────────────┘      └─────────────┘      └─────────────┘      └──────┬──────┘
                                                                          │
                                                                          ▼
                                                              ┌───────────────────────┐
                                                              │  90° 1/4" NPT Elbow   │
                                                              └───────────┬───────────┘
                                                                          │
                                                                          ▼
                                                              ┌───────────────────────┐
                                                              │  4" 1/4" NPT Nipple   │
                                                              │     (Outlet Tube)     │
                                                              └───────────┬───────────┘
                                                                          │
                                                                          ▼
                                                              ┌───────────────────────┐
                                                              │    SPARK IGNITER      │
                                                              │   (12V → 10kV Arc)    │
                                                              └───────────────────────┘

    ELECTRICAL CONTROL - SOLENOID CIRCUIT
    ══════════════════════════════════════

    12V Bus (+) ──────────────────────────────────────────┐
                                                          │
                                                          ▼
                                               ┌──────────────────┐
                                               │   12V SOLENOID   │
                                               │   (Normally      │
                                               │    Closed)       │
                                               │   ●──── IN (+)   │
                                               │   ●──── OUT (-)  │
                                               └────────┬─────────┘
                                                        │
       ┌────────────────────────────────────────────────┘
       │
       ▼
    ┌──────────────────────────────────────────────────┐
    │             SOLID STATE RELAY (SSR)              │
    │           (e.g., Fotek SSR-40DA)                 │
    │                                                  │
    │   LOAD SIDE              CONTROL SIDE            │
    │  ┌────────┐              ┌────────┐              │
    │  │ DC+    │◄─────────────┤ (+)    │◄── ESP32 GPIO 33
    │  │ DC-    │──────────────►(-)     │◄── ESP32 GND │
    │  └────────┘              └────────┘              │
    │      │                                           │
    └──────┼───────────────────────────────────────────┘
           │
           ▼
        12V Bus (-)

    ESP32 TO SSR + IGNITER WIRING
    ══════════════════════════════

    ESP32 DevKit
   ┌────────────────┐
   │   GPIO 33 ─────┼──────────►  SSR Control (+)
   │  (Solenoid)    │
   │      GND ──────┼──────────►  SSR Control (-)
   │                │
   │   GPIO 32 ─────┼──────────►  Igniter Module Trigger (+)
   │   (Igniter)    │
   │      GND ──────┼──────────►  Igniter Module GND
   └────────────────┘

   ⚠️  IGNITER NOTE: If igniter is just 12V-powered, use a second
       SSR or MOSFET to switch its 12V power via GPIO 32.

    ALTERNATIVE: MOSFET-BASED SWITCHING
    ════════════════════════════════════

                          12V Bus (+)
                              │
                    ┌─────────┴─────────┐
                    │                   │
                    ▼                   │
              ┌───────────┐             │
              │ SOLENOID  │             │
              │   12V     │             │
              └─────┬─────┘             │
                    │  ┌───────────┐    │
                    │  │  Flyback  │    │
                    │  │   Diode   │    │
                    │  │  1N4007   │    │
                    │  └─────┬─────┘    │
                    └────────┼──────────┘
                             │ Drain
                         ┌───┴───┐
    ESP32 GPIO 33 ──[1K]─┤ GATE  │  IRLZ44N (Logic-Level MOSFET)
                         └───┬───┘
                             │ Source
                             ▼
                         GND (Common)
```

---

## 4. Physical Input Controls

```
                               ┌─────────────────────────────────────────────────┐
                               │          PHYSICAL INPUT WIRING                   │
                               └─────────────────────────────────────────────────┘

    ⚠️  IMPORTANT: GPIO 34, 35, 36, 39 are INPUT-ONLY with NO internal pull-up!
        You MUST use external 10K pull-up resistors to 3.3V for buttons/switches.

    SPEED POTENTIOMETER (Analog Input)
    ═══════════════════════════════════

                     3.3V
                      │
              ┌───────┴───────┐
              │    10K POT    │
              │   ┌───────┐   │
              └───┤ WIPER ├───┴───────────► GPIO 34 (ADC)
                  └───────┘
                      │
                      ▼
                     GND

    DIRECTION BUTTON (Momentary, Normally Open)
    ════════════════════════════════════════════

                     3.3V
                      │
                     [10K]  ◄── External Pull-up (REQUIRED!)
                      │
                      ├─────────────────────► GPIO 35
                      │
                   ┌──┴──┐
                   │ DIR │   Momentary Push Button
                   └──┬──┘
                      ▼
                     GND

    FIRE THRUSTERS BUTTON (Momentary, Normally Open)
    ═════════════════════════════════════════════════

                     3.3V
                      │
                     [10K]  ◄── External Pull-up (REQUIRED!)
                      │
                      ├─────────────────────► GPIO 39 (VN)
                      │
                   ┌──┴──┐
                   │FIRE │   BIG RED BUTTON 🔴
                   └──┬──┘
                      ▼
                     GND

    ENABLE SWITCH (Toggle, SPST)
    ═════════════════════════════

                     3.3V
                      │
                     [10K]  ◄── External Pull-up (REQUIRED!)
                      │
                      ├─────────────────────► GPIO 36 (VP)
                      │
                   ┌──┴──┐
                   │ EN  │   Toggle Switch (ON = LOW)
                   └──┬──┘
                      ▼
                     GND

    COMBINED SCHEMATIC
    ═══════════════════

                                          3.3V Rail
                                             │
           ┌─────────────────────────────────┼────────────────────────────────────┐
           │            ┌────────────────────┼────────────────────┐               │
          [10K]        [10K]                [10K]             ┌───┴───┐           │
           │            │                    │                │ 10K   │           │
           ├───►GPIO35  ├───►GPIO39          ├───►GPIO36      │  POT  │           │
           │            │                    │                │ WIPER ├──►GPIO34  │
        ┌──┴──┐      ┌──┴──┐              ┌──┴──┐             └───┬───┘           │
        │ DIR │      │FIRE │              │ EN  │                 │               │
        └──┬──┘      └──┬──┘              └──┬──┘                 │               │
           └────────────┴────────────────────┴────────────────────┴───────────────┘
                                             │
                                            GND
```

---

## 5. ESP32 Pin Assignment Summary

```
                               ┌─────────────────────────────────────────────────┐
                               │              ESP32 DEVKIT PINOUT                 │
                               └─────────────────────────────────────────────────┘

                                    ┌─────────────────────┐
                                    │     ESP32 DEVKIT    │
                          EN  ──────┤ EN            D23   ├──────
                         VP  ───────┤ VP/36    ▲    D22   ├────── (I2C SCL)
                         VN  ───────┤ VN/39    │    TX0   ├────── Serial TX
                         D34 ───────┤ D34      │    RX0   ├────── Serial RX
                         D35 ───────┤ D35      │    D21   ├────── (I2C SDA)
                         D32 ───────┤ D32      │    D19   ├──────
                         D33 ───────┤ D33      │    D18   ├──────
                         D25 ───────┤ D25      │    D5    ├──────
                         D26 ───────┤ D26      │    D17   ├──────
                         D27 ───────┤ D27      │    D16   ├──────
                         D14 ───────┤ D14      │    D4    ├──────
                         D12 ───────┤ D12      │    D2    ├────── (LED)
                         D13 ───────┤ D13      │    D15   ├──────
                         GND ───────┤ GND      │    GND   ├────── GND
                         VIN ───────┤ VIN      │    3V3   ├────── 3.3V
                                    │     [USB PORT]      │
                                    └─────────────────────┘

    ╔═══════════════════════════════════════════════════════════════════════════════════════╗
    ║                               PIN ASSIGNMENT TABLE                                     ║
    ╠════════════╦═══════════════════════════════╦══════════════════════════════════════════╣
    ║   GPIO     ║   FUNCTION                    ║   NOTES                                  ║
    ╠════════════╬═══════════════════════════════╬══════════════════════════════════════════╣
    ║   POWER    ║                               ║                                          ║
    ║   VIN      ║   5V Power Input              ║   From 12V→5V step-down                  ║
    ║   GND      ║   Ground                      ║   Common ground (star topology)          ║
    ╠════════════╬═══════════════════════════════╬══════════════════════════════════════════╣
    ║   MOTOR    ║                               ║                                          ║
    ║   GPIO 25  ║   Motor Speed (PWM)           ║   Needs level shift to 5V                ║
    ║   GPIO 26  ║   Motor Direction             ║   HIGH=Forward, LOW=Reverse              ║
    ║   GPIO 27  ║   Motor STOP                  ║   HIGH=Force Stop                        ║
    ║   GPIO 14  ║   Motor ENABLE                ║   LOW=Enabled                            ║
    ╠════════════╬═══════════════════════════════╬══════════════════════════════════════════╣
    ║   EXHAUST  ║                               ║                                          ║
    ║   GPIO 33  ║   SSR Trigger (Solenoid)      ║   HIGH=Open solenoid                     ║
    ║   GPIO 32  ║   Igniter Trigger             ║   HIGH=Spark on                          ║
    ╠════════════╬═══════════════════════════════╬══════════════════════════════════════════╣
    ║   INPUTS   ║   (ALL NEED EXTERNAL PULLUP)  ║                                          ║
    ║   GPIO 34  ║   Speed Potentiometer (ADC)   ║   Analog input 0-3.3V                    ║
    ║   GPIO 35  ║   Direction Button            ║   10K pull-up to 3.3V REQUIRED           ║
    ║   GPIO 39  ║   Fire Thrusters Button       ║   10K pull-up to 3.3V REQUIRED           ║
    ║   GPIO 36  ║   Enable Switch               ║   10K pull-up to 3.3V REQUIRED           ║
    ╠════════════╬═══════════════════════════════╬══════════════════════════════════════════╣
    ║   COMMS    ║                               ║                                          ║
    ║   TX0/RX0  ║   Serial (via USB)            ║   Built-in USB-to-Serial                 ║
    ║   (int)    ║   WiFi                        ║   Built-in WiFi antenna                  ║
    ║   (int)    ║   Bluetooth Classic + BLE     ║   Built-in dual-mode Bluetooth           ║
    ╚════════════╩═══════════════════════════════╩══════════════════════════════════════════╝
```

---

## 6. Complete System Wiring

```
═══════════════════════════════════════════════════════════════════════════════════════════════════
                                    COMPLETE SYSTEM WIRING
═══════════════════════════════════════════════════════════════════════════════════════════════════

        ┌─────────────────────────────────────────────────────────────────────────────────────────┐
        │                                    24V SECTION                                          │
        │    ╔═══════════════════╗                                                                │
        │    ║   24V / 1000W     ║                                                                │
        │    ║     BATTERY       ║                                                                │
        │    ╚═════════╦═════════╝                                                                │
        │              ║                                                                          │
        │      (+)═════╬══════════════════════════════════════════════════════════════(+)         │
        │              ║          ┌───────────────────────────────────────────────┐    │          │
        │              ╠══════════►              24V BUS BAR (+)                  │◄═══╝          │
        │              ║          └───────────────────┬───────────────────────────┘               │
        │              ║                ┌─────────────┴─────────────┐                             │
        │              ║                ▼                           ▼                             │
        │              ║    ┌───────────────────────┐   ┌───────────────────────┐                 │
        │              ║    │   MOTOR CONTROLLER    │   │     24V → 12V         │                 │
        │              ║    │       (+24V IN)       │   │     STEP-DOWN         │                 │
        │              ║    └───────────┬───────────┘   └───────────┬───────────┘                 │
        │              ║                ▼                           │                             │
        │              ║    ┌───────────────────────┐               │                             │
        │              ║    │   24V/350W MOTOR      │               │                             │
        │              ║    └───────────────────────┘               │                             │
        │      (-)═════╬══════════════════════════════════════════════════════════════(-)         │
        │              ║          ┌───────────────────────────────────────────────┐    ▲          │
        │              ╠══════════►      24V BUS BAR (-)  [STAR GND]              │◄═══╝          │
        │              ║          └───────────────────────────────────────────────┘               │
        └─────────────────────────────────────────────────────────────────────────────────────────┘

        ┌─────────────────────────────────────────────────────────────────────────────────────────┐
        │                                    12V SECTION                                          │
        │              From 24V→12V Step-Down                                                     │
        │          ┌───────────────────────────────────────────────────┐                          │
        │          │                  12V BUS BAR (+)                  │                          │
        │          └──────────────────────┬────────────────────────────┘                          │
        │                   ┌─────────────┼─────────────┐                                         │
        │                   ▼             ▼             ▼                                         │
        │        ┌───────────────┐ ┌────────────┐ ┌────────────────┐                              │
        │        │  SSR + 12V    │ │  IGNITER   │ │  12V → 5V      │                              │
        │        │  SOLENOID     │ │   +12V     │ │  STEP-DOWN     │                              │
        │        └───────────────┘ └────────────┘ └───────┬────────┘                              │
        │                                                 ▼                                       │
        │                                         ┌───────────────┐                               │
        │                                         │   5V OUTPUT   │───► ESP32 VIN                 │
        │                                         └───────────────┘                               │
        └─────────────────────────────────────────────────────────────────────────────────────────┘

        ┌─────────────────────────────────────────────────────────────────────────────────────────┐
        │                                   ESP32 CONNECTIONS                                     │
        │                           ┌─────────────────────────────┐                               │
        │                           │         ESP32 DEVKIT        │                               │
        │   From 5V Step-Down ─────►│ VIN                    GND  │◄───── To 24V GND Bus          │
        │                           │                             │                               │
        │   ┌───────────────────────┤ GPIO 25 (PWM) ══[LEVEL]══►──┼───── Motor SPEED              │
        │   │  MOTOR            ┌───┤ GPIO 26 ────────────────────┼───── Motor DIRECTION          │
        │   │  CONTROLLER       │   │ GPIO 27 ────────────────────┼───── Motor STOP               │
        │   │  CONTROL ─────────┴───┤ GPIO 14 ────────────────────┼───── Motor ENABLE             │
        │   │                   ┌───┤ GPIO 33 ────────────────────┼───── SSR Control (+)          │
        │   │  EXHAUST ─────────┴───┤ GPIO 32 ────────────────────┼───── Igniter Control          │
        │   │                   ┌───┤ GPIO 34 (ADC) ◄─────────────┼───── Speed POT Wiper          │
        │   │  PHYSICAL         │   │ GPIO 35 ◄───[10K]───3.3V ───┼───── Direction Button         │
        │   │  INPUTS ──────────┤   │ GPIO 39 ◄───[10K]───3.3V ───┼───── Fire Button              │
        │   │                   └───┤ GPIO 36 ◄───[10K]───3.3V ───┼───── Enable Switch            │
        │   │                       │         [USB PORT]          │                               │
        │   │                       └─────────────────────────────┘                               │
        │   └─────────────────────────────► Motor Controller GND ─────► 24V GND Bus               │
        └─────────────────────────────────────────────────────────────────────────────────────────┘
═══════════════════════════════════════════════════════════════════════════════════════════════════
```

---

## 7. Safety Considerations

### Power System
- ⚡ **Main Fuse**: Install 50A fuse on 24V battery positive line
- ⚡ **Branch Fuses**: 20A motor, 10A 12V bus, 5A 5V bus

### Motor Control
- 🔄 **Flyback Protection**: Motor controller should have built-in protection
- 🛑 **Emergency Stop**: Physical E-STOP button recommended

### Exhaust System
- 🔥 **Propane Safety**: Close ball valve when not in use
- 💥 **Ignition**: Igniter should pulse, not run continuously; keep wires away from propane

### ESP32
- 📍 **Input Protection**: GPIO 34-39 are input-only; 3.3V max
- 📍 **Output Protection**: Never connect 5V directly to any GPIO

---

## 8. Bill of Materials (BOM)

| Qty | Component | Specifications | Notes |
|-----|---|---|---|
| 1 | Battery | 24V, 1000W (40+ Ah) | LiFePO4 recommended |
| 1 | DC-DC Converter | 24V→12V, 10A+ | Buck converter |
| 1 | DC-DC Converter | 12V→5V, 3A+ | For ESP32 + USB |
| 1 | Motor | 24V/350W Brushed | With gearbox, 10" wheel |
| 1 | Motor Controller | 24V/350W | With 0-5V speed input |
| 1 | ESP32 DevKit | Any variant | DOIT recommended |
| 1 | SSR | 3-32VDC control | Fotek SSR-40DA or similar |
| 1 | 12V Solenoid | NC, 1/4" NPT | Brass body preferred |
| 1 | Spark Igniter | 12V→10kV | Continuous duty |
| 1 | Propane Tank | 1lb | Standard camping size |
| 1 | Needle Valve | 1/4" NPT | Brass |
| 1 | Ball Valve | 1/4" NPT | Quarter-turn |
| 1 | NPT Elbow | 90°, 1/4" | Brass |
| 1 | NPT Nipple | 4", 1/4" | Brass |
| 1 | Potentiometer | 10K linear | Panel mount |
| 2 | Push Buttons | Momentary NO | Panel mount |
| 1 | Toggle Switch | SPST | Panel mount |
| 4 | Resistors | 10K, 1/4W | External pull-ups |
| 1 | Level Shifter | 3.3V↔5V | TXS0108E or BSS138 |
| 2 | Bus Bars | 4+ terminals | Power distribution |

### Wire Gauges
| Circuit | Current | AWG |
|---|---|-----|
| 24V Battery | 40A+ | 8 |
| Motor Controller | 15A | 14 |
| 12V Distribution | 10A | 16 |
| 5V/Signal | <1A | 22-24 |

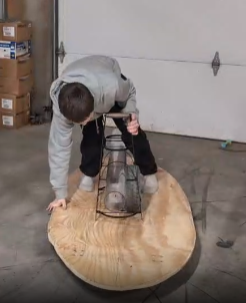
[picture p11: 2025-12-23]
space-tornado/build/front.png

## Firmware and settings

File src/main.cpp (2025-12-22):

#include <Arduino.h>
#include "config.h"
#include "logging.h"
#include "rocket_state.h"
#include "motor_control.h"
#include "physical_inputs.h"
#include "exhaust_control.h"
#include "wifi_manager.h"
#include "serial_interface.h"
#include "ble_interface.h"

void setup() {
    delay(1000); // Allow serial to initialize
    
    // Initialize logging first
    Logger.addLogger(Serial);
    Logger.println("\n\n=== Space Tornado Starting ===\n");
    
    // Initialize all systems
    initRocketState();
    initMotorControl();
    initPhysicalInputs();
    initExhaustControl();
    initSerialInterface();
    
    // Initialize BLE (NimBLE - for Web Bluetooth)
    initBLEInterface();
    
    // Initialize Bluetooth Classic (SPP - for serial terminal apps)
    initBluetoothClassic();
    
    // Initialize WiFi (non-blocking, will connect in background)
    initWiFi([]() {
        Logger.println("✅ WiFi connected - web interface available");
    });
    
    // Initialize OTA
    initOTA();
    
    Logger.println("✅ Space Tornado initialized and ready!");
}

void loop() {
    // Handle WiFi management (non-blocking)
    handleWiFiLoop();
    
    // Update physical inputs (potentiometer, buttons, switch)
    updatePhysicalInputs();
    
    // Update motor control (acceleration curve)
    updateMotorControl();
    
    // Update exhaust control
    updateExhaustControl();
    
    // Handle serial interface (terminal commands)
    updateSerialInterface();
    
    // Handle BLE interface (Web Bluetooth)
    updateBLEInterface();
    
    // Handle Bluetooth Classic interface (serial terminal apps)
    updateBluetoothClassic();
    
    // Small delay to prevent tight loop
    delay(10);
}

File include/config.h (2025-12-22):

#pragma once

// Pin assignments - adjust as needed
#define PIN_MOTOR_SPEED 25          // PWM output for motor speed (0-5V via voltage divider)
#define PIN_MOTOR_DIRECTION 26      // Direction control (LOW = Reverse, HIGH = Forward)
#define PIN_MOTOR_STOP 27           // Stop control (HIGH = Force Stop)
#define PIN_MOTOR_ENABLE 14         // Enable control (LOW = Enabled)

#define PIN_EXHAUST_SOLENOID 33     // SSR trigger for exhaust solenoid
#define PIN_EXHAUST_IGNITER 32      // Spark igniter control (if separate)

#define PIN_SPEED_POT 34            // Analog input for speed potentiometer
#define PIN_DIRECTION_BUTTON 35     // Direction button (with pull-up)
#define PIN_FIRE_BUTTON 39          // Fire thrusters button (with pull-up)
#define PIN_ENABLE_SWITCH 36        // Enable switch (with pull-up)

// Configuration constants
#define MAX_MOTOR_SPEED 100.0f      // Maximum motor speed percentage (0-100)
#define MAX_ACCELERATION 5.0f       // Maximum acceleration per second (percentage points)
#define SPEED_INCREMENT 10.0f       // Speed increment/decrement percentage (for terminal commands)
#define MOTOR_PWM_FREQUENCY 5000    // PWM frequency for motor speed control (Hz)
#define MOTOR_PWM_RESOLUTION 8      // PWM resolution in bits (0-255)
#define MOTOR_PWM_MAX_VALUE 255     // Maximum PWM value

// Timing constants
#define ACCELERATION_UPDATE_MS 50   // Update acceleration every 50ms
#define PHYSICAL_INPUT_DEBOUNCE_MS 50  // Debounce time for buttons/switches
#define SERIAL_COMMAND_TIMEOUT_MS 1000 // Timeout for serial command processing

// Web server
#define WEB_SERVER_PORT 80

// Bluetooth Classic (SPP)
#define BT_CLASSIC_DEVICE_NAME "SpaceTornado-SPP"

// BLE Configuration
#define BLE_DEVICE_NAME "SpaceTornado"
#define BLE_SERVICE_UUID        "4fafc201-1fb5-459e-8fcc-c5c9c331914b"
#define BLE_COMMAND_CHAR_UUID   "beb5483e-36e1-4688-b7f5-ea07361b26a8"
#define BLE_STATUS_CHAR_UUID    "beb5483f-36e1-4688-b7f5-ea07361b26a9"
#define BLE_STATUS_NOTIFY_INTERVAL_MS 500

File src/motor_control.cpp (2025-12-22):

#include "motor_control.h"
#include "config.h"
#include "rocket_state.h"
#include "logging.h"
#include <Arduino.h>

void initMotorControl() {
    // Configure motor control pins
    pinMode(PIN_MOTOR_DIRECTION, OUTPUT);
    pinMode(PIN_MOTOR_STOP, OUTPUT);
    pinMode(PIN_MOTOR_ENABLE, OUTPUT);
    
    // Configure PWM for speed control
    ledcSetup(0, MOTOR_PWM_FREQUENCY, MOTOR_PWM_RESOLUTION);
    ledcAttachPin(PIN_MOTOR_SPEED, 0);
    
    // Initialize to safe state
    digitalWrite(PIN_MOTOR_STOP, LOW);      // Not stopped
    digitalWrite(PIN_MOTOR_ENABLE, HIGH);   // Disabled initially
    digitalWrite(PIN_MOTOR_DIRECTION, HIGH); // Forward
    ledcWrite(0, 0);                        // Zero speed
    
    Logger.println("✅ Motor control initialized");
}

float calculateAcceleratedSpeed(float currentSpeed, float targetSpeed, float deltaTimeSeconds) {
    if (deltaTimeSeconds <= 0.0f) {
        return currentSpeed;
    }
    
    float difference = targetSpeed - currentSpeed;
    
    // If already at target, return it
    if (abs(difference) < 0.1f) {
        return targetSpeed;
    }
    
    // Calculate maximum change per second (percentage points)
    float maxChangePerSecond = MAX_ACCELERATION;
    
    // Calculate maximum change for this time period
    float maxChange = maxChangePerSecond * deltaTimeSeconds;
    
    // Apply logarithmic curve: change rate is proportional to remaining difference
    // This creates smooth acceleration/deceleration
    float changeRate = abs(difference) / 100.0f; // Normalize to 0-1
    float logarithmicFactor = log10(1.0f + changeRate * 9.0f); // Log curve: 0 to ~1
    float adjustedMaxChange = maxChange * (0.3f + 0.7f * logarithmicFactor); // Scale between 30-100% of max
    
    // Limit change to adjusted maximum
    float change = (difference > 0) ? 
        min(adjustedMaxChange, difference) : 
        max(-adjustedMaxChange, difference);
    
    return currentSpeed + change;
}

void updateMotorControl() {
    unsigned long currentTime = millis();
    float deltaTimeSeconds = (currentTime - rocketState.lastSpeedUpdate) / 1000.0f;
    
    // Update acceleration curve
    if (deltaTimeSeconds > 0.001f) { // Only if significant time has passed
        // Update current speed using acceleration curve
        if (isEnabled() && !isEmergencyStop()) {
            rocketState.currentSpeed = calculateAcceleratedSpeed(
                rocketState.currentSpeed, 
                rocketState.targetSpeed, 
                deltaTimeSeconds
            );
            
            // Update direction immediately (no acceleration curve for direction)
            rocketState.currentDirection = rocketState.targetDirection;
        } else {
            // System disabled or emergency stop - decelerate to zero
            rocketState.currentSpeed = calculateAcceleratedSpeed(
                rocketState.currentSpeed, 
                0.0f, 
                deltaTimeSeconds
            );
        }
        
        rocketState.lastSpeedUpdate = currentTime;
        
        // Update approximate velocity (simple integration)
        // This is a rough approximation - actual velocity would require more complex calculations
        float speedChange = rocketState.currentSpeed - (rocketState.approximateVelocity * 100.0f / MAX_MOTOR_SPEED);
        rocketState.approximateVelocity += speedChange * deltaTimeSeconds * 0.01f; // Scale factor
        rocketState.approximateVelocity = max(0.0f, rocketState.approximateVelocity); // Clamp to positive
    }
    
    // Apply motor control outputs
    if (isEmergencyStop() || !isEnabled()) {
        // Emergency stop or disabled
        digitalWrite(PIN_MOTOR_STOP, HIGH);     // Force stop
        digitalWrite(PIN_MOTOR_ENABLE, HIGH);   // Disable
        ledcWrite(0, 0);                        // Zero speed
    } else {
        // Normal operation
        digitalWrite(PIN_MOTOR_STOP, LOW);      // Not stopped
        digitalWrite(PIN_MOTOR_ENABLE, LOW);    // Enable motor controller
        
        // Set direction
        digitalWrite(PIN_MOTOR_DIRECTION, rocketState.currentDirection ? HIGH : LOW);
        
        // Set speed (0-255 PWM value from 0-100% speed)
        // Note: Motor controller expects 0-5V, ESP32 outputs 0-3.3V
        // May need voltage divider or level shifter - check motor controller specs
        uint8_t pwmValue = (uint8_t)((rocketState.currentSpeed / MAX_MOTOR_SPEED) * MOTOR_PWM_MAX_VALUE);
        ledcWrite(0, pwmValue);
    }
}

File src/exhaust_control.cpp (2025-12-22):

#include "exhaust_control.h"
#include "config.h"
#include "rocket_state.h"
#include "logging.h"
#include <Arduino.h>

void initExhaustControl() {
    pinMode(PIN_EXHAUST_SOLENOID, OUTPUT);
    pinMode(PIN_EXHAUST_IGNITER, OUTPUT);
    
    // Initialize to safe state (solenoid closed, igniter off)
    digitalWrite(PIN_EXHAUST_SOLENOID, LOW);
    digitalWrite(PIN_EXHAUST_IGNITER, LOW);
    
    Logger.println("✅ Exhaust control initialized");
}

void updateExhaustControl() {
    // Control exhaust system based on firing state
    if (isFiringThrusters() && isEnabled() && !isEmergencyStop()) {
        // Fire thrusters: open solenoid and activate igniter
        digitalWrite(PIN_EXHAUST_SOLENOID, HIGH);  // Open solenoid (SSR trigger HIGH)
        digitalWrite(PIN_EXHAUST_IGNITER, HIGH);   // Activate spark igniter
    } else {
        // Stop thrusters: close solenoid and deactivate igniter
        digitalWrite(PIN_EXHAUST_SOLENOID, LOW);   // Close solenoid
        digitalWrite(PIN_EXHAUST_IGNITER, LOW);    // Deactivate spark igniter
    }
}
